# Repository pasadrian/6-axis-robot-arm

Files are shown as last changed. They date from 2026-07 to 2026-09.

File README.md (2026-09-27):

# 6-Axis Robotic Arm

## 1. Introduction
The main goal of this project was to create a 6-DoF robotic arm that is "mostly" 3D printed.  
\* "mostly" means that all custom parts are 3D printed, relying only on commonly available components like screws, timing belts, and ball bearings.

This approach provides several key benefits:
- **Modular construction**: 3D printing allows for easy design improvements and modular upgrades.
- **Easy maintenance**: Repairs are fast and cheap, eliminating the need to order specific parts.
- **Safety**: The lightweight design allows operators to work safely near the robot without the risk of serious injuries.

The arm's architecture is based on standard 6-DoF industrial manipulators. This makes it an ideal educational platform. It mimics the robots future engineers will encounter, but remains forgiving of operator mistakes.

---

## 2. Design
All 3D printed components were custom designed by the author in FreeCAD. The entire robot was manufactured using PLA on a Bambu Lab A1 printer equipped with a standard 0.4 mm nozzle.

---

## 3. Electronics & Actuation
- **Stepper Motors**: NEMA 17 and NEMA 23 stepper motors drive the primary axes, chosen for their torque and wide availability among hobbyists (see Chapter 5.1 in Masters_Thesis.pdf).
- **Servomotors**: The wrist and end effector utilize 180° servomotors. These are recommended for their low weight. Since most grippers are symmetrical, a 180° range is fully sufficient for standard operations.
- **Controller**: An STM32H755ZI-Q microcontroller serves as the main board, selected for its reliability, high processing speed, and hardware FPU necessary for real-time kinematics.

---

## 4. Control & Software
- **Communication**: A Serial (UART) connection is used to transmit data between the operator's PC and the STM32 board.
- **Interface**: The operator's GUI was developed in Python. It handles user inputs and sends movement commands directly to the microcontroller.

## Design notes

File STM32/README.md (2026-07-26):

# 6-axis-robot-arm
Project of a 3D printed 6axis robotic arm controlled with STM32 and Python GUI

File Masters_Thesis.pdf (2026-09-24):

AKADEMIA GÓRNICZO-HUTNICZA IM. STANISŁAWA STASZICA W KRAKOWIE

WYDZIAŁ ELEKTROTECHNIKI, AUTOMATYKI, INFORMATYKI I INZYNIERII BIOMEDYCZNEJ ˙

## Praca dyplomowa

## Design, Construction, and Control of a 6-DoF Robotic Arm Manufactured Using 3D Printing

## Projektowanie, budowa i sterowanie szescioosiowym ´ ramieniem robota wykonanym w technologii druku 3D

Autor: | inz. Adrian Pa ˙ | s´
Kierunek studiów: | Automatyka i Robotyka
Opiekun pracy: | dr hab. inz. Adam Piłat, prof. u. ˙

Kraków, 2026

## Contents

1 Introduction | 5
2 Literature review and existing solutions | 6
3 Project assumptions and constraints | 9
4 Mechanical design | 11
5 Actuation and electronics | 17
6 Mathematical model | 20

3

7 Software | 29
8 Validation and testing | 33
9 Conclusions | 41

4

A.Pas´ | Introduction

## 1 Introduction

### 1.1 Aim of this thesis

In modern factories, automation and robotization have become crucial in improving efficiency, precision, and safety. Industrial manipulators are increasingly used to replace or assist humans in tedious or hazardous tasks, such as palletizing, assembly, and conveyor belt operations. This generates a need for highly qualified engineers with the skills to design, program, and maintain robotic systems.
However, training future engineers on industrial robots is not practical due to the high cost of manipulators, costly fixing and maintenance, and the safety related to operating a machine with such a high payload. There is a clear need for affordable, safe, and easy to fix robots that mimic the kinematics and control used in industrial standards.
The main aim of this thesis is to design, construct, and evaluate a fully functional 6 DoF articulated robotic arm intended for educational purposes. The primary objective was to create a platform that mimics the configuration and control logic of industrial manipulators, while remaining safe for human interaction, affordable, and easy to maintain. Using 3D printing technology and combining an STM32 microcontroller with a Python control system, this project provides a perfect tool to study advanced robotics, such as inverse kinematics, joint synchronization, and path planning.

### 1.2 Scope of this thesis

This thesis is structured into several chapters that describe the entire process of designing, constructing, and programming the robotic arm, with functional testing of the physical platform. Following this introduction, Chapter 2 provides examples of existing robotic arms and similar open source projects. Chapter 3 defines the project assumptions, such as mechanical, electronic and safety constraints. In Chapters 4 and 5, these constraints are implemented, starting with mechanical design, CAD modeling, and torque calculations, to the selection of actuators, electronics, and the main control unit. Chapter 6 focuses on the mathematical model of the manipulator and explains forward and inverse kinematics with path planning and joint synchronization algorithms. Chapter 7 presents the software used, communication protocols, and the graphical user interface with the simulation tools. Chapter 8 evaluates the performance of the completed arm with load tests and trajectory verification. Finally, Chapter 9 provides a conclusion, summarizes the experimental results, and discusses potential real-life applications and future improvements for the system.

5

Literature review and existing solutions | A.Pas´

## 2 Literature review and existing solutions

The topic of robotic manipulators dates back to 1954, when the first hydraulic arm was invented and constructed in the United States.[1] Since then, many improvements have been made. Today, not only are there many types of robotic manipulators, but also most of them are equipped with numerous sensors and cameras.

### 2.1 Robotic manipulators - classification and application

Robotic arms can be divided into the classification presented in Fig. 1. Each of the constructions has its own advantages and disadvantages.

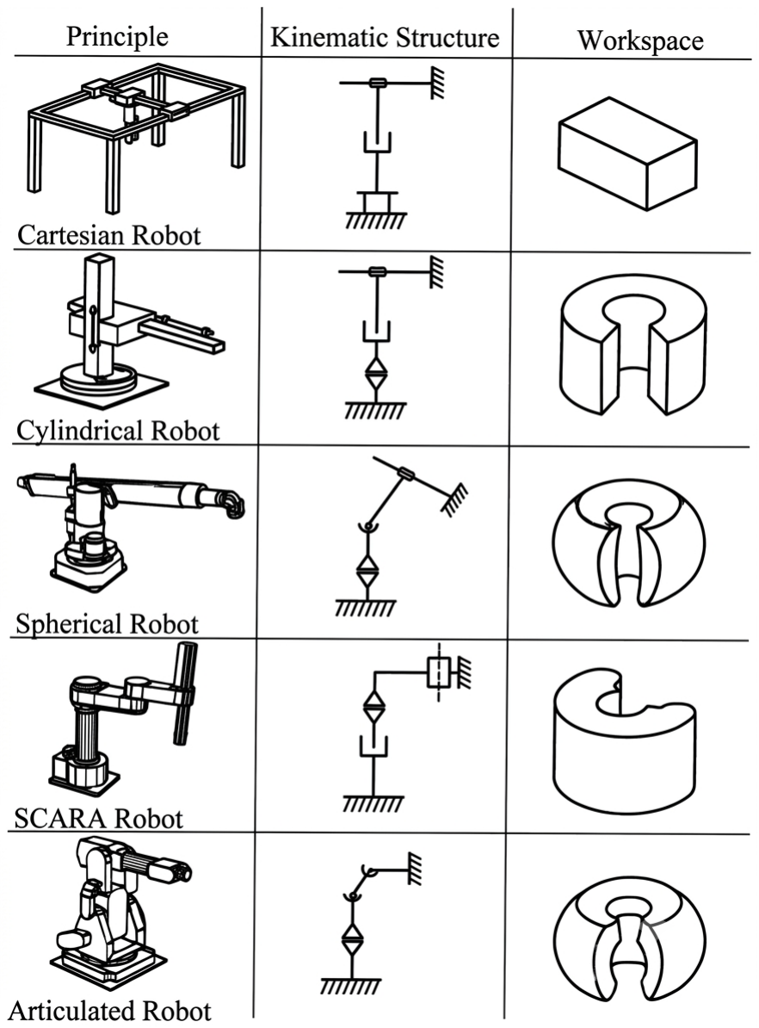
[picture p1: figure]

Figure 1. Classification of robotics manipulators [2].

The first group consists of cartesian manipulators, which are the simplest to control. The main drawback is the platform that has a large volume, usually greater than the robot’s workspace. The best example of this mechanism is an overhead crane.
The second category are robots that stand on their own on a rotating base. This type is the most common in industrial applications. For example, SCARA robots are commonly used by conveyor belts or whenever parts need to be moved with high precision. For other, general purpouse applications the articulated robots are almost always used. They have all of their joints as rotational, which allows for the greatest flexibility. This is the type of robot that is presented in this thesis. They can be found in assembly lines for cars, welding applications, or palletizing. That is why there are numerous brands that sell this type of robot. The most popular are Fanuc, Kuka, or ABB.

6

A.Pas´ | Literature review and existing solutions

### 2.2 Different ways of constructing a robotic arm

Robotic manipulators for industrial applications are generally made with metal as they need to be rigid to withstand huge loads. Because of that, their construction has a number of constraints. They are extremely heavy, require huge motors, consume a lot of power, and are dangerous to people standing in their operating range. All of those issues make it impractical for any other application than industrial applications.
Another way of making robotic arms is 3D printing. This technique allows for the creation of safer robots. Those plastic versions, although less accurate, repetable, or rigid, are the exact copy of the metal manipulators when it comes to construction. That makes them the perfect candidates for use in schools as a training tool for future engineers. In addition, if something goes wrong, making spare parts and fixing the 3d printed manipulator takes much less time and money.

### 2.3 Existing projects of 6-DoF manipulators

As robotic arms are extremely common in industrial applications, there is a great deal of them, ranging from big companies to hobbistic models. The following are some examples of the most popular ones.

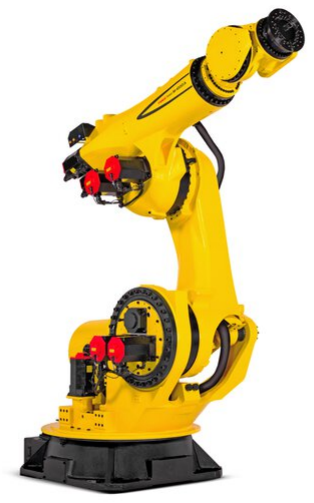
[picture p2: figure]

Figure 2. Fanuc M-1000iA [3].

7

Literature review and existing solutions | A.Pas´

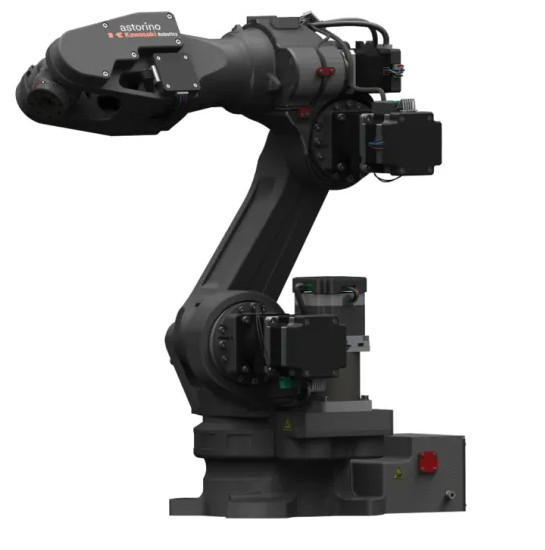
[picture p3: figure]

Figure 3. Educational robot Astorino [4].

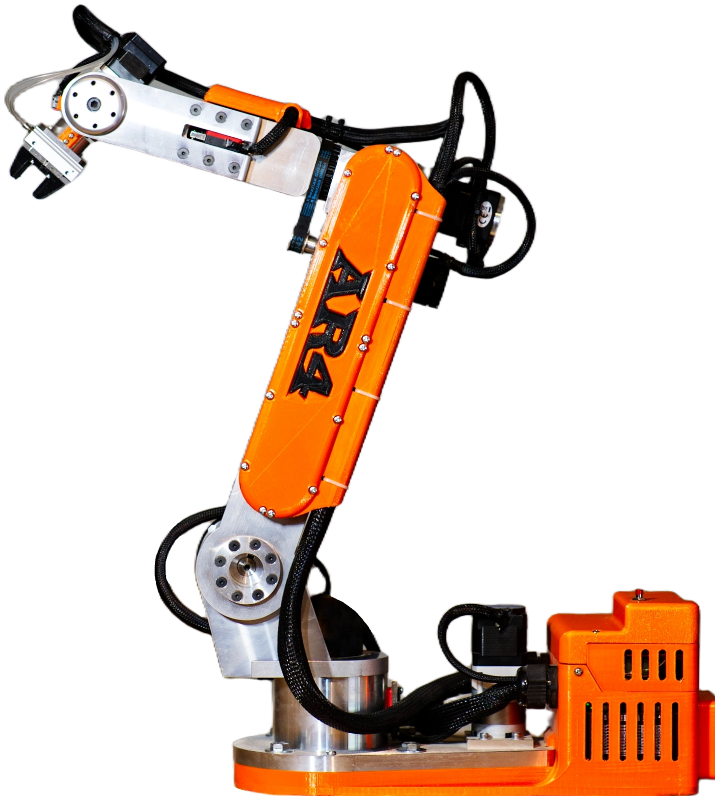
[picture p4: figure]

Figure 4. AR4 hobbist educational robot [5].

8

A.Pas´ | Project assumptions and constraints

## 3 Project assumptions and constraints

The main goal of this project was to design a manipulator that closely follows the architecture of industrial robotic arms while remaining safe for human interaction. To ensure that the robot is functional and reliable, several mechanical, operational, electronic, and safety constraints had to be defined.

### 3.1 Mechanical constraints

A key assumption was to implement a 6-degree-of-freedom (6-DOF) structure. This configuration mimics industrial standards, where the first three joints position the wrist in space and the remaining three determine the orientation of the end effector. This setup ensures that the control logic and kinematics of the robot are kept similar to those of the industrial manipulators. Material selection was another important constraint. Since the robot is mostly 3D-printed, it was necessary to choose a filament that balances ease of printing with structural integrity. The chosen material had to provide enough precision for the gear teeth and bearings while being fast enough to print larger components. The final design aims to be rigid enough to prevent flexing under its own weight, yet light enough to be powered by hobbyist-grade motors.

### 3.2 Operational parameters

The operational group of assumptions involves the robot’s physical capabilities, such as reach and motion limits

– Reach: The maximum reach was determined by the 3D printer’s build plate size. Arm
| links were designed to be as large as the printer could handle.

– Motion Limits: Each joint has a defined range of motion for two reasons. First, it pre-
| vents cables from tangling or breaking during rotation. Second, it allows the use of limit
| switches for the homing procedure, which establishes a "zero" position in space.

– Load Capacity: High strength was not a priority for this project. Since the structure
| is plastic, heavy loads could cause the links to bend or crack over time. The robot is
| intended for light tasks, such as moving small objects or playing board games, where the
load is negligible.

### 3.3 Electronic constraints

Electronic constraints are just as important as mechanical ones and can be divided into three categories: the main control unit, the motors, and the power supply.

| 9

Project assumptions and constraints | A.Pas´

The main constraint in selecting the control unit was computational performance. For a six degree of freedom manipulator, the kinematics equations are quite heavy, so a board with a high speed microprocessor and floating point support was necessary. Another factor was the number of inputs and outputs. Since the project uses many motors, limit switches, and sensors, the board must handle all of them simultaneously without any lag.
The second group of components are the motors. Here, torque, weight, cost, and power consumption needed to be balanced. A compromise had to be established between all these parameters. For the base axis, which holds the weight of the entire arm, torque was the priority over weight and cost. However, for the joints further up the arm, weight became the most important factor, the lighter the motor, the better. The overall cost was kept low since this is a hobbyist project made of 3D printed plastic parts, and using expensive industrial motors would be overkill.
The last thing to consider was the power supply. The main power consumption comes from the motors. It was assumed that the operating voltage should be maximized within the limits of the drivers. This will ensure that the motors maintain a high level of torque, even at higher speeds.

### 3.4 Safety constraints

The safety constraints in this project are mainly focused on the control and motion of the robotic arm. Unlike heavy industrial robots made of steel, which can pose a significant danger to operators, the manipulator built in this thesis is 3D printed and operates at lower power levels. This design results in a much lower risk for humans as the motors do not provide enough force to cause serious injury.
The main safety concerns are actually related to the robot itself, as collisions with other objects could easily damage the manipulator. To prevent this, software limitations were implemented. The first was the virtual boundarie to keep the end effector from hitting the ground and other known obstacles. The second was to limit each joint to make it work within a safe operating range so that the robot would not tangle its cables or hit itself.

10

A.Pas´ | Mechanical design

## 4 Mechanical design

The robotic arm was fully designed and built by the author of this thesis. The design is based on standard robotic manipulators, but the main goal was to see how many parts could be 3D printed. Using 3D printing makes the robot much easier to repair because there is no need to wait for expensive or specialized parts from a shop. If something breaks, a new part can be printed.
The entire project was designed in FreeCAD. This program was chosen because it is free and works locally on the computer, so it does not require a cloud connection or a user account. Additionally, using this software means the author has full control and ownership of all the designs without any licensing problems.

### 4.1 CAD model of the manipulator

The following figure shows the complete 3D model of the robotic arm (without the gripper), with a list of parts on the left.

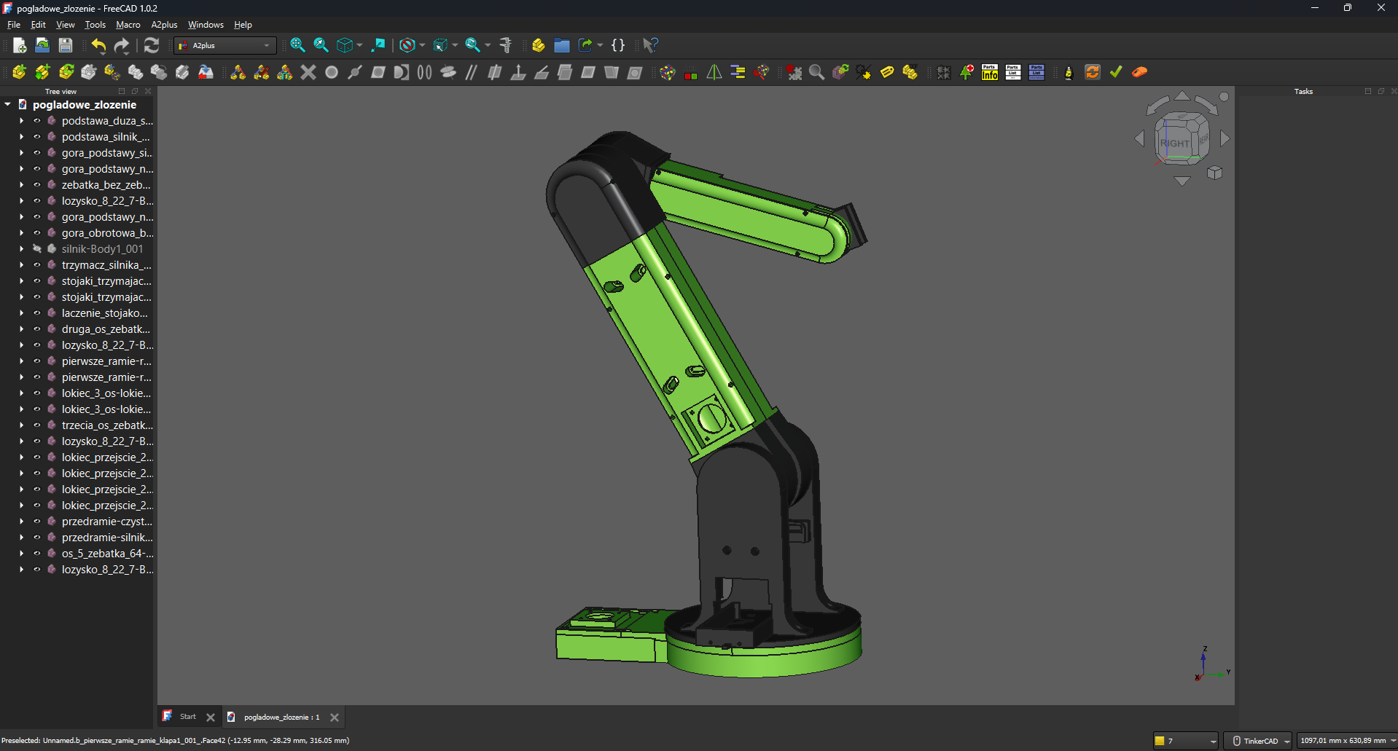
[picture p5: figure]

Figure 5. Complete model of the robotic arm in FreeCAD. Source: Own work

The manipulator consists of 24 3D-printed parts, including:

– gears with 32, 64, and 128 teeth,

– custom-designed "lazy susan" ball bearings,

– timing belt tensioners.

11

Mechanical design | A.Pas´

Specialized bearings were designed for the main base turntable, the elbow, and the forearm. This helped reduce the overall weight of the robot and, more importantly, allowed custom bearing sizes that perfectly fit the design. These bearings use 5mm metal balls and a 3D-printed race with even spacing to keep the balls in place while allowing them to spin freely. As mentioned

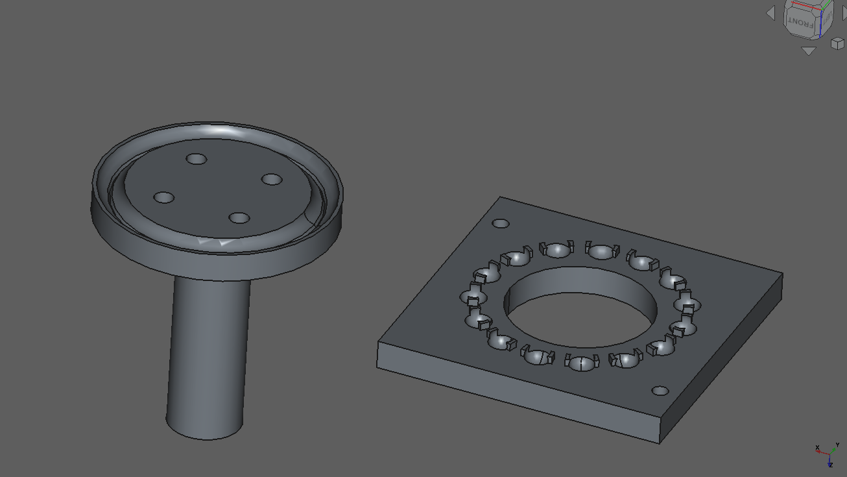
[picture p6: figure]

Figure 6. Custom ball bearing design. Source: Own work

above, the main goal was to design a functional robotic arm using as few standard parts as possible. In addition to electronics, the only components that need to be purchased are threaded inserts, screws, small standard bearings, timing belts, and metal balls.
Although these parts must be purchased, they are all standard, widely available products. They are not specific to this single project, so they are always in stock and easy to find. This fulfills the main goal of the thesis: creating a robotic arm primarily from 3D-printed materials without being dependent on specialized suppliers.

### 4.2 Mechanical specifications and dimensions

After completing the CAD model, the physical limits and dimensions of the manipulator were established. Defining these parameters is essential for understanding the robot’s workspace and for future calculations in the control software.
The reach of the robot is determined by the lengths of the individual links measured between the rotation axes of the joints.

– Base height (Link 0): 187.3 mm – from the ground to the center of the shoulder joint.

12

A.Pas´ | Mechanical design

– Upper arm (Link 1): 335.6 mm – from the shoulder to the elbow joint.

– Forearm (Link 2): 228.6 mm - from the elbow to the center of the wrist.

– Wrist to TCP (Link 3): 212 mm – from the center of the wrist to the end of the gripper.

To provide a quick overview of the robot’s capabilities, the most important technical specifications are presented in the table below.

Table 1. General technical specifications of the manipulator.

Parameter | Value
Architecture | 6-Axis Articulated Robot
Maximum Reach (Radius) | 776.2 mm
Total Weight | approx. 4.4 kg
Main Material | PLA (3D Printed)
Drive System | NEMA 17 and 23 Stepper Motors
Transmission | GT2 Timing Belts / 3D Printed Gears
Estimated Payload | Up to 500 g with 1/16 microsteps
Base Diameter | 220 mm

### 4.3 Calculating torque for two main joints

To ensure that the stepper motors were capable of holding the manipulator, it was necessary to calculate the required torque for the two main joints, the second and third, which are the most stressed during the operations. The most demanding position is when the robotic arm is fully extended horizontally.
The torque for each individual part was calculated using the following formula:
M = m · g · r | (1)
where m is the mass of the component in kg, g is the gravitational acceleration (9.81 m/s² | ), and

r is the distance from the center of mass of the part to the axis of the joint in meters.
The mass of each 3D-printed part was obtained from the Bambu Studio slicer, while the mass of the motors was taken from their datasheets [6]. For these calculations, it was assumed that the center of gravity for each part lies at its geometric center. The weight of minor components such as screws, nuts, and timing belts was considered negligible.
The table below presents the torque calculation for the second joint (Shoulder), which uses a NEMA 23 motor.

13

Mechanical design | A.Pas´

Table 2. Torque calculation for Nema23 (Axis 2)

Item | Weight [kg] Center of Gravity [m] Torque [Nm]
nema17 + bearing | 0.289 | 0.070 | 0.201
arm bearing | 0.012 | 0.179 | 0.021
arm | 0.210 | 0.154 | 0.324
arm gear | 0.014 | 0.179 | 0.025
elbow | 0.089 | 0.319 | 0.284
elbow gear | 0.041 | 0.334 | 0.137
elbow bearing | 0.012 | 0.334 | 0.038
entire elbow | 0.084 | 0.334 | 0.282
nema17 + bearing (2) | 0.289 | 0.294 | 0.849
small motor | 0.132 | 0.405 | 0.535
forearm | 0.104 | 0.480 | 0.497
axis 5 bearings | 0.012 | 0.567 | 0.065
axis 5 gear | 0.014 | 0.567 | 0.081
axis 6 holder | 0.015 | 0.605 | 0.088
servo sg995 | 0.055 | 0.620 | 0.341
pointer | 0.011 | 0.711 | 0.080
Total Sum | | | 3.847

The total torque of 3.85 Nm is higher than the maximum holding torque for the chosen Nema23 motor (57HS112-3004), which is around 3 Nm in the datasheet [7]. To overcome this, a gear ratio of 128:20 (6.4:1) was applied on this axis.
The same was done for the third joint (Elbow).

14

A.Pas´ | Mechanical design

Table 3. Torque calculation for Nema17 (Axis 3)

Item | Weight [kg] Center of Gravity [m] Torque [Nm]
nema17 + bearing | 0.289 | -0.040 | -0.115
small motor | 0.132 | 0.071 | 0.092
forearm | 0.104 | 0.146 | 0.148
axis 5 bearings | 0.012 | 0.233 | 0.026
axis 5 gear | 0.014 | 0.233 | 0.033
axis 6 holder | 0.015 | 0.271 | 0.039
servo sg995 | 0.055 | 0.286 | 0.154
pointer | 0.011 | 0.377 | 0.042
Total Sum | | | 0.419

Here again, the total torque exceeds the maximum holding torque for the motor used Nema17 (HS4401), which is 0.4 Nm according to the datasheet [6].To overcome this, a gear ratio of 8:1 was applied on this axis.

### 4.4 Optimalization for 3D printing

Optimizing the design for 3D printing is an essential part of the process. Several constraints and techniques must be considered during the design phase.

– The size of the 3D printer build plate.

– The printer’s precision and layer height.

– Wall thickness and infill percentage.

– Printing time, while not the most critical factor, printing smaller parts reduces the risk of total failure during long jobs.

The printer used for this project was a Bambu Lab A1. It has a build volume of 256 × 256 × 256 mm³
. All parts were printed using a standard 0.4 mm nozzle, as it provides a good balance between printing speed and detail. The layer height was set to 0.2 mm. To ensure that parts are strong enough but still lightweight, most structural elements were designed with a total thickness of 5 mm. This thickness consists of 3 layers of the outer wall on each side, with a 15% infill between. This combination provides great rigidity while keeping the weight of the robotic arm low.
In addition to these settings, certain design techniques can significantly improve the quality of the robot.

15

Mechanical design | A.Pas´

– Proper orientation of the object on the build plate.

– Using supports only where necessary.

– Splitting large designs into smaller, connected parts.

In Fused Deposition Modeling (FDM) in 3D printing, the internal bond of the filament is almost always stronger than the adhesive bond between the printed layers [8]. Because of this, the printing orientation was the most important parameter. Choosing the right orientation was always a priority, even if it required more supports or a longer printing time.

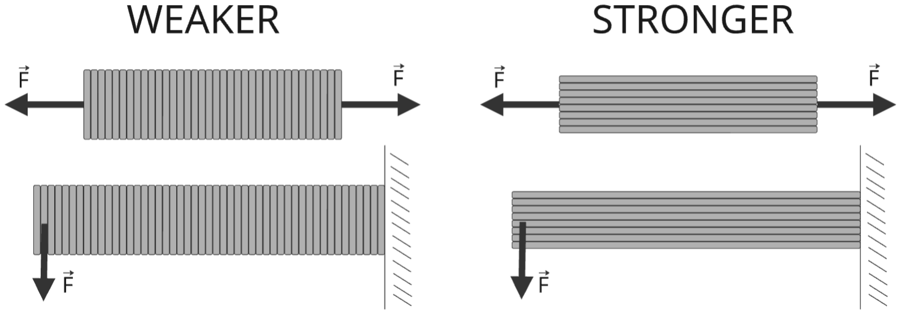
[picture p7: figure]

Figure 7. Comparison of strength based on printing orientation. Source: Own work

Another important factor is deciding when to use supports. A good way to optimize the design is to eliminate the need for supports by changing the geometry. For example, a 90-degree overhang can often be replaced with a slope (chamfer) to make it self-supporting. This saves material and avoids the "ragged" surface finish that supports often leave behind.
The final technique used was to split the design into smaller components. Although it is usually easier to print one large part, splitting is useful in two cases. First, it allows for better access to the inside of a part to install gears or cables. Second, it makes assembly easier by providing more space for tools, such as screwdrivers, during the final build.

16

A.Pas´ | Actuation and electronics

## 5 Actuation and electronics

### 5.1 Motors with gears

When selecting drivers in robotics there are two main options to consider, servomechanizm or stepper motor. The servomechanizm is every DC or AC motor with closed control loop, for example, brushless motor with encoder and PID controler which allows it to reach the desired position. The second type is a stepper motor. This driver does not require feedback, it can be controlled in an open loop, as it does not rotate freely, but takes steps. This type of motor is more common in hobby designs, as it is easier to use and cheaper.
In this project, both stepper and servomotors are used. The first five axes are equipped with Nema23 and Nema17 stepper motors, while the sixth axis and gripper use servo 180. Nema stepper motors were chosen as they have a high torque while being affortable. Every stepper motor has 200 steps per revolution [6] and is set to work with 1/16 microstepping. In addition, to achieve higher precision, gear ratios were used for all axes. The resulting resolution for each joint is summarized below:

Table 4. Kinematic parameters and step resolution for each axis.

Axis | Motor Type | Gear Ratio Steps/Rev Resolution [◦
/step]
1 | Nema17 HS4401 | 8:1 | 25,600 | 0.01406
2 | Nema23 57HS112-3004 | 128:20 | 20,480 | 0.01758
3 | Nema17 HS4401 | 8:1 | 25,600 | 0.01406
4 | Nema17 HS4401 | 1:1 | 3,200 | 0.11250
5 | Nema17 HS4023 | 4:1 | 12,800 | 0.02812
6 | Servo SG995 | 1:1 | N/A | N/A

Based on the data in Table 4 some observations can be made. The precision on the first three axes, which are responsible for positioning the wrist of the robot in a space, is less than 0.02◦

per step, which is more than enough for simple pick and place operations. The fourth axis has the lowest precision and no gear ratio, because it only rotates the forearm of the robot. The sixth axis is equipped with a servomotor that can rotate in 180◦
and its resolution is based mainly on applied control via PWM signal.
Another aspect of gear ratio is the increase in a torque liniary to the ratio applied. The torques for each motor can be seen in the following table:

17

Actuation and electronics | A.Pas´

Table 5. The torques of each motor. [6], [9], [10], [7]

Axis | Motor Type | Motor’s torque [Nm] Gear Ratio Joint’s torque [Nm]
1 | Nema17 HS4401 | 0.4 | 8:1 | 3.2
2 | Nema23 57HS112-3004 | 3 | 128:20 | 19.2
3 | Nema17 HS4401 | 0.4 | 8:1 | 3.2
4 | Nema17 HS4401 | 0.4 | 1:1 | 0.4
5 | Nema17 HS4023 | 0.14 | 4:1 | 1.6
6 | Servo SG995 | 1 | 1:1 | 1

Motors and gear ratios were chosen independently for each joint. As the second axis holds the whole robotic arm it had to be the strongest one. The first, third and fourth axes were given the same motor, but different gear ratios. Although the first and third have some load to overcome, the fourth joint does not need much strength since it only spins the forearm. The fifth axis was equipped with a smaller Nema17 motor to reduce weight. The last sixth axis has serwo 180◦
. With the assumption that every gripper used in its build is simetrical, there was no need for a more advanced motor.

### 5.2 Positioning and feedback

To accurately position the robotic arm in 3D space, it is essential to establish a reference coordinate system. This is achieved with a process known as homing. The manipulator is equipped with five end-stop sensors, one for each axis. During homing, the control system sets the speed of each motor to the slow safety value and sets the direction to move toward the endstop. When end-stop is activated, the link stops and waits for other to finish homing. Once all of the joints are finished, the robot sets this position as home to know the relative orientation of each axes. From now on, the controller tracks the position of the stepper motors based on the amount of steps each took. Since stepper motors provide predictable motion, they can operate effectively without external feedback, assuming that the load does not exceed the motor’s holding torque, which would result in lost steps. Similarly, the 180◦
servomotor does not need external feedback, as its closed loop circuitry maintains the shaft position based on the width of the incoming PWM (Pulse Width Modulation) signal.

### 5.3 Control unit - uC, drivers

The STM32H755ZI-Q microcontroller was selected as the central processing unit for the robotic manipulator. It is an extremely powerful board characterized by the following parameters [11]:

18

A.Pas´ | Actuation and electronics
- Dual-core architecture: Featuring Cortex-M7 and Cortex-M4 cores with a clock speed of up to 480 MHz. This high computational power, supported by a hardware Floating Point Unit (FPU), is essential for real time Inverse Kinematics (IK) calculations and trajectory planning.
- Extensive I/O capabilities: Up to 114 I/O ports with interrupt support. This allows for future upgrades, such as implementing closed loop control with encoders on each axis, adding extra sensors, or integrating manual control interfaces.
- Advanced Timers (PWM): High resolution timers allow for precise PWM generation to control servos and provide stable interrupt signals for stepper motor drivers, to keep the motor speeds as it was planned.
- Communication Protocols: A wide range of interfaces including I2C, SPI, and UART, which was used in this project for remote robot control.

While simpler controllers would be suitable for this application, this high-performance board is ideal for future expanding the robot’s capabilities.
Each stepper motor is equipped with its own driver. For the Nema23 motor on the second axis, a DM556 driver was used to handle a higher current and provide greater torque. The remaining axes use TMC2209 drivers, chosen for their quiet operation and smooth motion control.

### 5.4 Electronic diagram

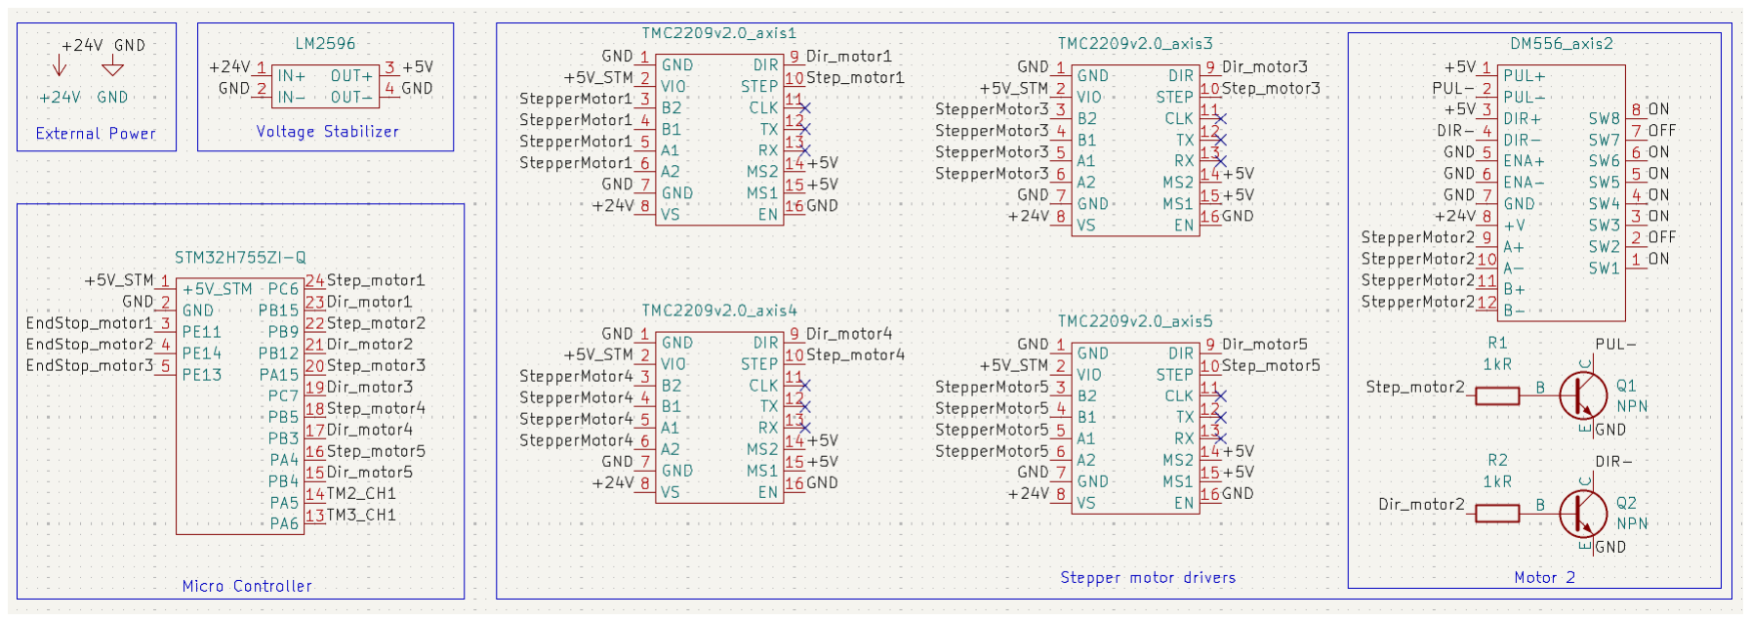
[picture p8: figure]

Figure 8. Electrical scheme. Source: Own work

19

Mathematical model | A.Pas´

## 6 Mathematical model

This chapter is based on the work presented in [12].

### 6.1 Froward kinematics

To successfully control a robotic manipulator, it is essential to understand how the arrangement of each joint affects the position and orientation of the end effector. Based on the length of each robot’s link and the angels at which the joints are set, the exact pose of the manipulator’s end effector can be calculated. For 6-DOF robotic arms, the Denavit–Hartenberg convention is used. This method describes rotation and translation between consecutive joints with standarised parameters, as shown in the table below.

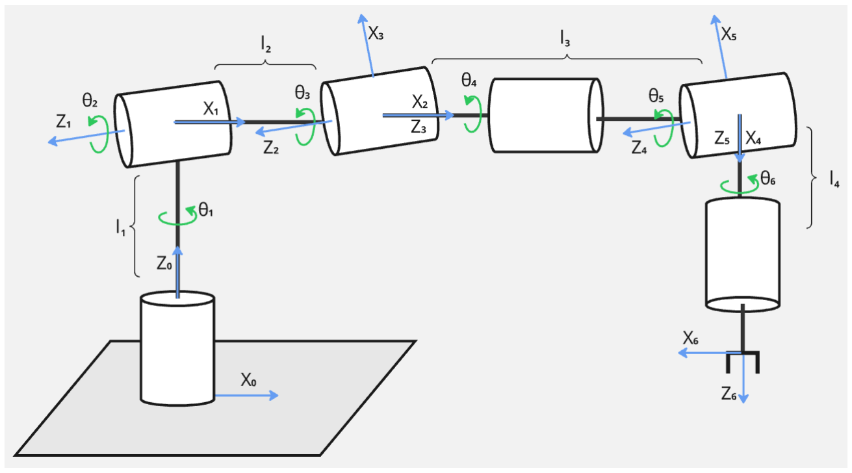
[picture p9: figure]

Figure 9. Rotation frames for my robot. Source: Own work

These parameters can be applied to the general D-H matrix (2), which describes the rotation and translation of the joint-link pair.

Ti =

cos θi | − sin θi cos αi | sin θi sin αi | ai cos θi
sin θi | cos θi cos αi | − cos θi sin αi | ai sin θi
0 | sin αi | cos αi | di
0 | 0 | 0 | 1

(2)

By substituting the values into the matrix, we get the following 6 matrices.

20

A.Pas´ | Mathematical model

Table 6. Denavit–Hartenberg parameters for 6-DOF robotic arm.

i | ai | αi | di | θi
1 | 0 | +π
| | 2 | l1 | θ1
2 l2 | 0 | 0 | θ2
3 l3 | 0 | 0 | θ3
4 | 0 | +π
| | 2 | 0 | θ4
5 | 0 | − π
| | 2 | 0 | θ5
6 | 0 | 0 | l4 | θ6

T1 =

cos θ1 | 0 | sin θ1 | 0
sin θ1 | 0 − cos θ1 | 0
0 | 1 | 0 | l1
0 | 0 | 0 | 1

(3)

T2 =

cos θ2 | − sin θ2 | 0 l2 cos θ2
sin θ2 | cos θ2 | 0 l2 sin θ2
0 | 0 | 1 | 0
0 | 0 | 0 | 1

(4)

T3 =

cos θ3 | − sin θ3 | 0 l3 cos θ3
sin θ3 | cos θ3 | 0 l3 sin θ3
0 | 0 | 1 | 0
0 | 0 | 0 | 1

(5)

T4 =

cos θ4 | 0 | sin θ4 | 0
sin θ4 | 0 − cos θ4 | 0
0 | 1 | 0 | 0
0 | 0 | 0 | 1

(6)

T5 =

cos θ5 | 0 | − sin θ5 | 0
sin θ5 | 0 | cos θ5 | 0
0 | −1 | 0 | 0
0 | 0 | 0 | 1

(7)

T6 =

cos θ6 | − sin θ6 | 0 0
sin θ6 | cos θ6 | 0 0
0 | 0 | 1 l4
0 | 0 | 0 1

(8)

21

Mathematical model | A.Pas´

Because the movement of the earlier joints influences the pose of all of the following joints, multiplying the matrices results in the final homogeneous transformation matrix defining the end effector pose relative to the base of the robot.

T

0
6 = T1 T2 T3 T4 T5 T6 =

"
R3×3 | p3×1
01×3 | 1
, | (9)

Where R3x3 is a rotation matrix and p3x1 is a vector of the position of the end effector.

### 6.2 Inverse kinematics

When dealing with robotic manipulators, one of the fundamental problems is determining the angles of each joint to achieve the required position and orientation of the end effector. This problem, known as inverse kinematics, is not trivial. Firstly, there can be more than one solution or no solution at all for the given configuration of the end effector. Additionally, not every manipulator has an analytical closed form solution for the inverse kinematics. There are two conditions that must be met. The first one is that three of the manipulator’s joints must be parrarel. The second is that there needs to be a sphirical joint, which means that three of its joints must have a rotation axis that intersects in a common point. The robot described in this thesis meets those requirements, which allows the inverse kinematics problem to be solved. As a starting point, the homogeneous transformation matrix T
0/6 is given. As explained in the previous chapter, this matrix contains a rotation matrix R⁰
6

and a position vector P

0
6 of the
end effector.
Due to the presence of a spherical wrist, the inverse kinematics problem can be divided into two independent ones. The first three joints are responsible for the position of the robot’s wrist, while the last three define its orientation. With that, the problem comes to computing the position of the wrist and the orientation R⁶
3 of the last three joints. First, by moving one joint back from the known location of the end effector, the exact position of the wrist can be calculated.

W =

wx
wy
wz

- =

px − d6r13

py − d6r23

pz − d6r33

- (10)

Here, the position is taken from P

0
6 = [px, py, pz]

T

and rnm is taken from R⁰
6

### 6.2.1 Position of the wrist

With the wrist pose known, the first part of the problem can simply be referred to as follows.

22

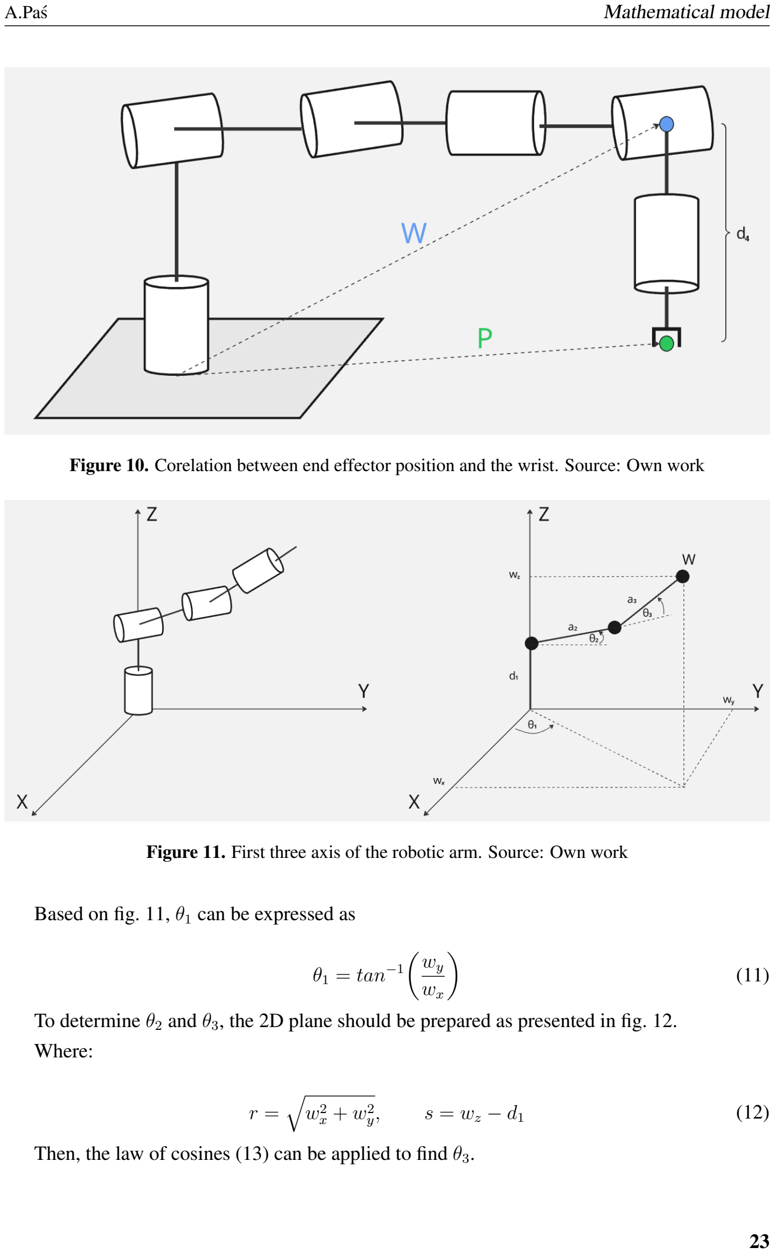
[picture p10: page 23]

A.Pas´ | Mathematical model

Figure 10. Corelation between end effector position and the wrist. Source: Own work

Figure 11. First three axis of the robotic arm. Source: Own work

Based on fig. 11, θ1 can be expressed as

θ1 = tan⁻¹

wy
wx
(11)

To determine θ2 and θ3, the 2D plane should be prepared as presented in fig. 12. Where:

r =

q
w²

x + w²
y

, s = wz − d1
(12)

Then, the law of cosines (13) can be applied to find θ3.

23

Mathematical model | A.Pas´

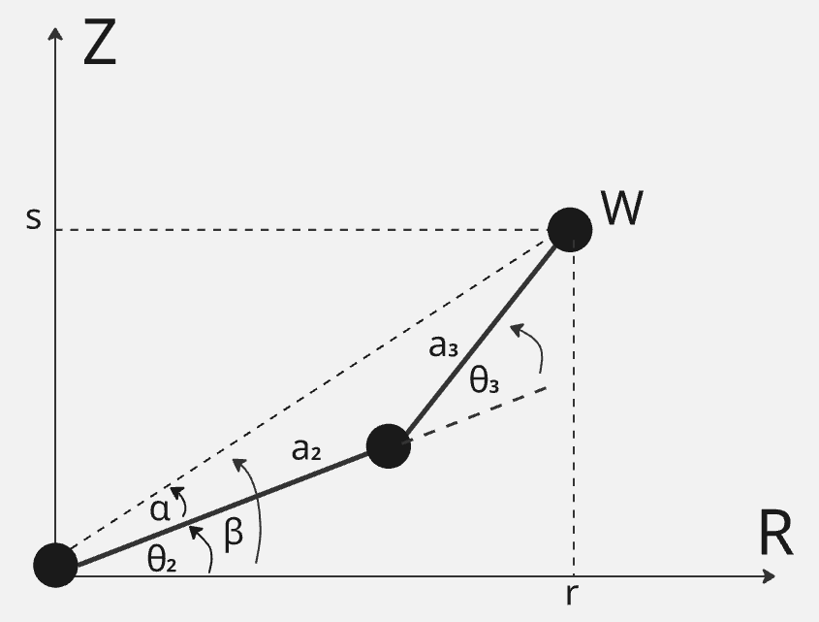
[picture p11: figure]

Figure 12. 2D plane with first and second manipulator’s arms. Source: Own work

c

2 = a

2 + b

2 − 2ab cos γ | (13)

With values assigned earlier, the final equation takes the following form:

θ3 = cos⁻¹

r

2 + s

2 − a

2
2 − a

2
3
2a2a3
| (14)

The final step is to determine θ2, which can be calculated as θ2 = α − β, where the angles

are defined as
α = atan2(s, r) | (15)
β = atan2(a3 sin θ3, a2 + a3 cos θ3) | (16)
θ2 = atan2(s, r) − atan2(a3 sin θ3, a2 + a3 cos θ3) | (17)

### 6.2.2 Orientation of the wrist

Now, the wrist orientation must be calculated. It is represented by the matrix R³
6
| , which can be
calculated from:
R

3
6 =
R

0/3T
R

0
6 | (18)

The R⁰
6

is known because it is our desired orientation. The R⁰
3
can be taken from T | 0/3, which is
the multiplication of the matrices T1..3 from the previous chapter and is equal to

24

A.Pas´ | Mathematical model

T

3
0 =

c1c23 | −c1s23 | s1 | wx
s1c23 | −s1s23 | −c1 | wy
s23 | c23 | 0 | wz
0 | 0 | 0 | 1

(19)

The same can be done with the matrix R³
6

, as it is a part of the transformation matrix T 3/6,
which is a multiplication of matrices T4..6.

T

3
6 =

c4c5c6 − s4s6 | −c4c5s6 − s4c6 | c4s5 | px
s4c5c6 + c4s6 | −s4c5s6 + c4c6 | s4s5 | py
−s5c6 | s5s6 | c5 | pz
0 | 0 | 0 | 1

(20)

Now, substituting the rotation matrices into the equation (18) and performing the transformation, the following equation is obtained.
c4c5c6 − s4s6 | −c4c5s6 − s4c6 | c4s5
s4c5c6 + c4s6 | −s4c5s6 + c4c6 | s4s5
−s5c6 | s5s6 | c5

- =

c1c23 | s1c23 | s23
−c1s23 | −s1s23 | c23
s1 | −c1 | 0

r11 | r12 | r13
r21 | r22 | r23
r31 | r32 | r33

(21)

From this equality five crucial equations can be written:

c4s5 = c1c23r13 + s1c23r23 + s23r33 | (22)
s4s5 = −c1s23r13 − s1s23r23 + c23r33 | (23)
c5 = s1r13 − c1s23 | (24)
s5s6 = s1r12 − c1r22 | (25)
−s5c6 = s1r11 − c1r22 | (26)

Now, the three remaining angles θ4, θ5, and θ6 depend only on the angles determined previously. For θ5 first the sin(θ5) can be calulated and then used in the atan2 function.

s5 =

q
1 − c

2
5 | (27)

θ5 = atan2
±

p
1 − (s1r13 − c1r23)

2

, s1r13 − c1r23
(28)

25

Mathematical model | A.Pas´

By dividing equations (23) and (22), θ4 can be obtained.

θ4 = atan2

− c1s23r13 − s1s23r23 + c23r33, c1c23r13 + s1c23r23 + s23r33
(29)

Identical for the last angle, by taking (25) and (26) and dividing them, θ6 can be obtained:

θ6 = atan2
s1r12 − c1r22, −s1r11 + c1r22
(30)

### 6.3 Summary of inverse kinematics and constraints

The equations presented in the following allow to calculate the required angles for all six joints.

θ1 = tan⁻¹

wy
wx
(11)
θ2 = atan2(s, r) − atan2(a3 sin θ3, a2 + a3 cos θ3) | (17)

θ3 = cos⁻¹

r

2 + s

2 − a

2
2 − a

2
3
2a2a3
| (14)

θ4 = atan2

− c1s23r13 − s1s23r23 + c23r33, c1c23r13 + s1c23r23 + s23r33 | (29)

θ5 = atan2
±

p
1 − (s1r13 − c1r23)

2

, s1r13 − c1r23 | (28)

θ6 = atan2
s1r12 − c1r22, −s1r11 + c1r22 | (30)

In theory, this system of equations can result in up to 8 different sets of solutions for a single target position. For example, the robot could reach a point with its "elbow" pointing up or down. To make sure that the robot’s motion is predictable, there is an algorithm that always prioritizes the same solution from the available ones. This means that if both solutions are allowed by the set limits of the robot, the software will always choose the same one.
In this project, no joint rotates by more than 180 degrees. This restriction is mainly made to ensure that cables do not get tangled, but it also helps the IK by removing some of the theoretical solutions. The operational ranges for each joint are presented in the table below.

Table 7. Software and mechanical limits for each joint.

Joint | Minimum Angle | Maximum Angle
θ1 (Base) | -90.0° | 45.0°
θ2 (Shoulder) | 10.0° | 135.0°
θ3 (Elbow) | -170.0° | 0.0°
θ4 (Wrist Roll) | -90.0° | 90.0°
θ5 (Wrist Pitch) | -90.0° | 90.0°
θ6 (Wrist Yaw) | -90.0° | 90.0°

26

A.Pas´ | Mathematical model

Another critical aspect of the movement is the presence of singularities. A singularity occurs when two or more axes align in a straight line, causing the robot to lose a degree of freedom. The most common example is the position where the wrist is located directly above the base. In this state, the calculation for θ1 becomes unstable because any rotation of the base results in the same tool position. To ensure correct operation, the software constantly checks for known singularities and prevents the robot from entering them.

### 6.4 Algorithms of TCP control

The Tool Center Point (TCP) algorithm is a control method designed to move a robotic arm’s end effector along a specific trajectory while keeping the pose or orientation. This is essential in practical applications, such as

– Palletization tasks: Where a robot must move an object from point A to point B while keeping it perfectly level or at a specific angle.

– Welding or gluing: Where the distance and angle to the surface must be kept constant throughout the whole movement.

To make the algorithm work correctly, there are three functions that need to be implemented:

### 6.4.1 Path linearization and interpolation

Since the main goal of TCP movement is controlling the trajectory, the desired path needs to be "forced" onto the robotic arm. This is done by dividing the long path into many small segments. Without this division, the manipulator would move in a trajectory that is efficient for its joints but completely unpredictable for the user. Using smaller steps, the robot is forced to visit each point in sequence. If these points are close enough together, the robot basically moves in the exact straight line it was told to follow. Additionally, managing these shorter steps makes it much easier to keep the end effector in the desired orientation throughout the whole move.

### 6.4.2 Joint synchronization

Once the path is divided into microsteps, the movements of all six joints must be synchronized. If the joints operated independently, some might reach their target position faster than others, resulting in a jittery motion where the robot repeatedly stops and starts. In a synchronized system, the controller calculates the necessary velocity for each axis so that they all start and finish each microstep simultaneously. This ensures a smooth, continuous motion of the Tool Center Point.
In this project, the synchronization was implemented by choosing the leading joint. The process follows these steps:

27

Mathematical model | A.Pas´

– Step to angle conversion: First, the software takes the target angles from the IK equations and calculates the exact number of steps each motor must perform.

– Identifying the bottleneck: Using the predefined maximum safe speed for each motor, the controller calculates the minimum time required for each joint to complete its portion of the move:

tjoint =

steps to perform
max speed [steps/s]

– Leading joint selection: The joint that requires the most time to finish its move becomes the leading joint. This joint will move at its maximum allowed speed, acting as the speed bottleneck for the entire system.

– Velocity scaling: To ensure all motors finish at the exact same time, the speeds of the remaining five joints are scaled down proportionally:

Target Speedn =

stepsn

tlead

This approach ensures two things. First, all movements are safe because no motor ever exceeds its set speed limit. Second, all joints start and finish their rotation at the same time, eliminating the need for any motor to stop and wait, resulting in smooth continuous motion.

### 6.4.3 Look-ahead and velocity planning

To achieve smooth motion, the robot should avoid unnecessary acceleration and deceleration at every intermediate point. This is managed through Look-Ahead planning. Instead of just looking at the current move, the algorithm calculates several points in advance to analyze the next segments of the path. It checks each individual joint to see if it needs to continue moving in the same direction or not. If the direction stays the same, the controller prevents the motor from decelerating and maintains its current speed. However, if an axis needs to stop or change direction in the next step, the system starts to decelerate early to prepare for that change. This approach allows the robot to operate at its maximum efficient speed while maintaining mechanical stability and avoiding jerky movements.

28

A.Pas´ | Software

## 7 Software

Several different software tools were used to complete this thesis. Programs like FreeCAD, Bambulab Studio, and KiCad were used mainly for mechanical and electrical design. On the other hand, Python and STM32CubeIDE were chosen to handle the robot’s control system and all its functionalities.

### 7.1 Programming languages used

Two main programming languages were used in this project: Python for the high-level control on the PC, and C for the low-level logic running on the STM32 mainboard.

### 7.1.1 Python

Python was chosen because it is one of the best languages for creating a Graphical User Interface (GUI) for easy remote control. It offers numerous libraries that simplify development. One of them is Tkinter, which was used to set up the control window with buttons, sliders, and text boxes. Additionally, the NumPy library was used to handle all the complex matrix calculations needed for the robot’s movement. To make the system easier to debug, the Matplotlib library was also implemented to create a 3D simulation of the robot. This allows the user to visualize and test the trajectory on the screen before the real robotic arm starts moving.

### 7.1.2 C

C was chosen as it is the main language used in STM32CubeIDE. It is a very efficient and fast language that gives the programmer great control over the hardware. This speed is essential for a robot controller that needs to work in real-time, especially when calculating Inverse Kinematics (IK) and checking safety constraints simultaneously. Using C also allows for direct management of the microcontroller’s internal timers and interrupts, which is crucial for generating precise steps for the motors and responding to sensor data without any delay.

### 7.2 Communication computer - robot

Several communication methods were possible, but a serial connection (UART) was chosen for this project. It is easy to set up over a standard USB port that connects the computer directly to the STM32 board. This standard is fast enough to ensure that there is no visible delay between sending a command and the robot performing the movement. A baud rate of 115200 was selected as it offers a great balance between communication speed and data reliability.

29

Software | A.Pas´

Most of the communication is one-way, following a "command-action" structure. The computer sends a specific data packet that the board receives, processes, and then executes. To ensure that the robot knows exactly when a full command has arrived, each string is terminated with a newline character (\n). This acts as a trigger for the STM32 to start processing the received data.
However, for certain tasks, two-way communication is necessary to ensure that the system stays synchronized:

– Homing procedure: The computer sends the homing command and waits for a "ready" confirmation from the board once all axes have reached their limit switches.

– IK movement: After receiving the coordinates, the STM32 notifies the computer when the movement is finished. This prevents the PC from sending new coordinates before the robot is ready for the next step.

### 7.3 Graphical User Interface (GUI)

To make the robot easy to operate, a dedicated Graphical User Interface (GUI) was developed using Python and the Tkinter library. The interface allows the user to monitor the robot’s status and choose between different control modes. At the very top, a status indicator shows whether the robot is "Ready" or "Busy" (occupied).
As shown in Figure 13, the interface is divided into several sections:
1. Inverse Kinematics (IK) Control: This section allows the user to input Cartesian coordinates (X, Y, Z) and orientation angles (Roll, Pitch, Yaw). Once the "Perform IK Move" button is pressed, the PC sends the raw data to the STM32 which calculates how to move the arm to that exact point.
2. Demo Mode: This part is used to trigger pre-programmed demonstration sequences. It is particularly useful for showing smooth TCP movements along a chosen axis without manual input.
3. Homing: The large orange button starts the homing procedure. This must be used every time the robot is powered on so that the controller can find the "zero" position for each joint using the limit switches.
4. Manual Joint Control: This section allows for the movement of each of the first five axes individually. The user can also adjust the "delay" value, which directly changes the speed of the stepper motors by increasing or decreasing the time between steps.

30

A.Pas´ | Software
5. Accessories (Servos): These sliders control the two servos located at the end of the arm. One slider rotates the sixth axis (the wrist), and the other opens or closes the gripper.
6. Vision System and Calibration: This section handles camera based control. It allows the user to start the camera, calibrate the robot’s coordinate system with the camera’s view (using ArUco markers), and enable hand tracking mode.
7. Relative Step Debugging: This is a low level tool used for testing and maintenance. It allows the user to move a specific motor by a precise number of steps in either direction.

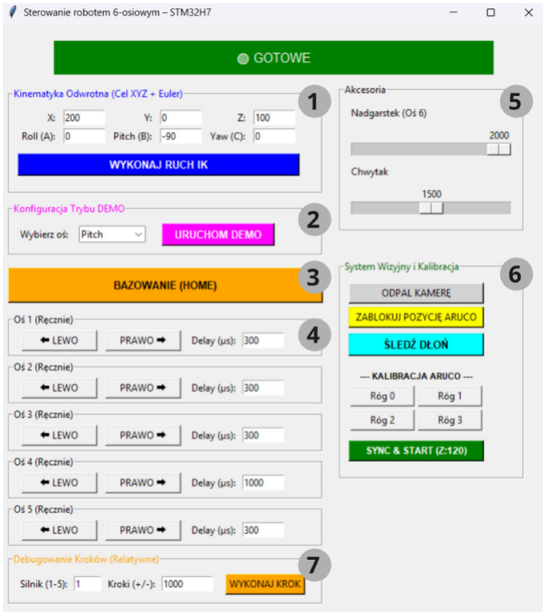
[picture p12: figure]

Figure 13. The Graphical User Interface designed for controlling the robotic arm. Source: Own work

31

Software | A.Pas´

### 7.4 Simulation and IK debugging

Before testing inverse kinematics on the physical robot, a simulation tool was created using the Matplotlib library. This tool was crucial for debugging, as it allowed a safe verification of the mathematical model. The simulation displays the robot’s pose from four different perspectives: a 3D view and three 2D projections (top, side, and front).
The user can input the coordinates (X, Y, Z) and orientation angles (Roll, Pitch, Yaw) to see how the virtual arm positions itself. At the bottom of the interface, the program displays the number of motor steps that each axis needs, to reach that position from the home state.
This function was extremely helpful during the testing. This allowed for a comparison. The coordinates were entered into the simulation and then each joint of the real robot was moved by the calculated number of steps. By checking if the real end effector ended up in the same spot as the virtual one, the accuracy of the IK algorithm could be confirmed with the reduced risk of accidental collisions.

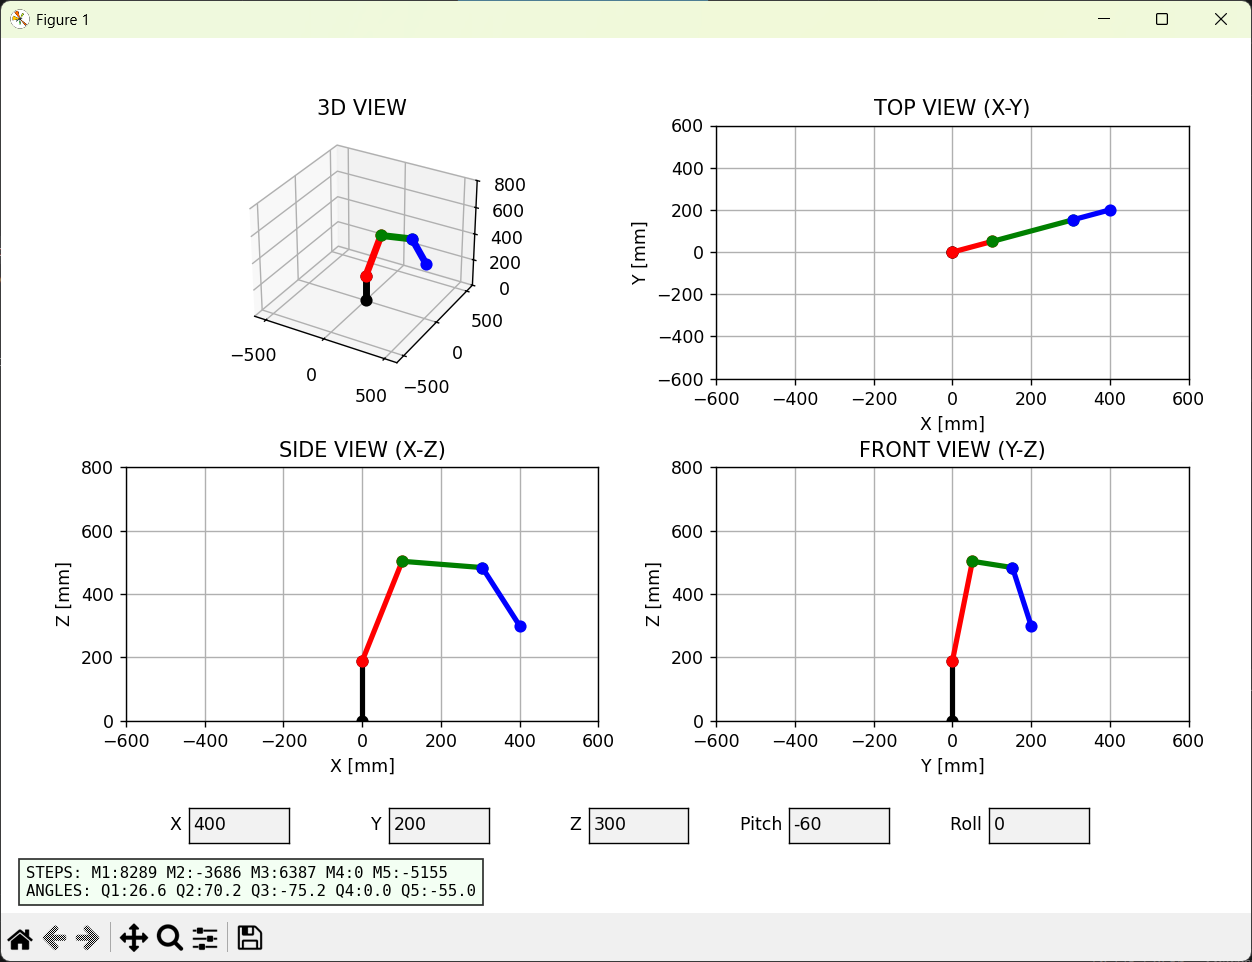
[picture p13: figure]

Figure 14. Python simulation used for Inverse Kinematics verification and debugging. Source: Own work

32

A.Pas´ | Validation and testing

## 8 Validation and testing

### 8.1 Load tests

To evaluate the physical capabilities of the robot, a series of load tests were conducted. This experiment aimed to determine the maximum payload that the arm could carry at its maximum reach. The experimental setup is shown in Figure 15.

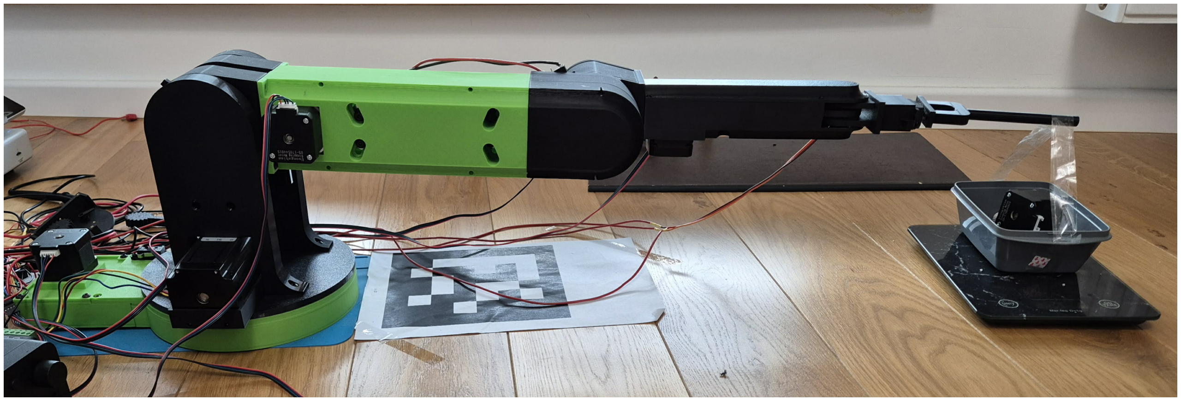
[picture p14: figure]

Figure 15. Experimental setup for measuring the robot’s lifting capacity. Source: Own work

The main bottlenecks in the robot’s lifting capacity are the second joint (shoulder) and the third joint (elbow), as they must overcome the largest torque. For this reason, the test was split into two independent tests. Each test focused on one of these joints while keeping all other axes in a locked constant position.
The tests analyzed the impact of two key variables: the microstepping ratio and the peak current supplied to the stepper motor driver.

### 8.1.1 Shoulder joint (joint 2) evaluation

In the second joint, a NEMA 23 stepper motor is used and controlled by a DM556 driver. During the test, the microstep ratio was compared between a full step (1:1) and a microstep (1:16), which corresponds to 200 and 3200 steps per revolution, respectively. In addition, two peak current limits were tested: a lower value of 2.7 A and a higher value of 4.9 A. The results of these measurements are presented in Table 8.

33

Validation and testing | A.Pas´

Table 8. Load capacity test results for Joint 2 (Shoulder).

Joint Microstepping Peak Current [A] Max Payload [g]

2 | 1:1 | 2.7 | 130
2 | 1:1 | 4.9 | 150
2 | 1:16 | 2.7 | 150
2 | 1:16 | 4.9 | 180

The payload values in the table represent the rounded average of several measurements. As expected, supplying a higher current to the motor increased its torque, allowing the arm to lift more weight. However, doubling the peak current from 2.7 A to 4.9 A resulted in only about a 15% to 20% increase in lifting capacity.
An interesting finding was the impact of microstepping. Changing the driver setting from full steps (1:1) to (1:16) microsteps increased the lifting strength by approximately 15% at 2.7 A and 20% at 4.9 A. Theoretically, increasing the microstepping ratio should decrease the holding torque because the rotor is forced to hold positions between the magnetic poles. However, in this setup, microstepping significantly reduced vibrations and jerk.
To show why this happens, the distance that the end effector moves during a single step can be calculated.

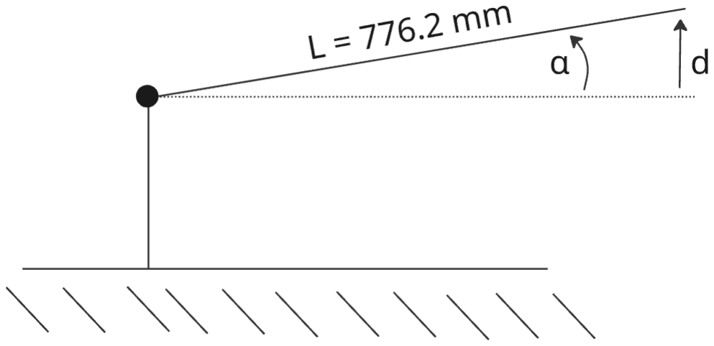
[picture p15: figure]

Figure 16. Displacement of end effector. Source: Own work

For a full step (1:1) mode, the motor rotates by α1:1 = 360◦/200 = 1.8

- per step. Assuming

a straight-line approximation for such a small angle, the displacement d1:1 of the robot’s end

34

A.Pas´ | Validation and testing

effector during a single step is:

d1:1 = L · sin(α1:1) = 776.2 mm · sin(1.8

◦
) ≈ 24.38 mm | (31)

For the (1:16) microstepping mode, the step angle is reduced to α1:16 = 360◦/3200 = 0.1125◦ per step. This results in a displacement d1:16 of:

d1:16 = L · sin(α1:16) = 776.2 mm · sin(0.1125◦
) ≈ 1.52 mm | (32)

This shows that, in full-step mode, each single step tries to move the end effector by almost 25 mm. Because the arm is 3D-printed, this sudden displacement generates huge forces, making the arm to wobble and causing the motor to fail under lighter loads than it sould. With the (1:16) microstepping ratio, the distance is just 1.5 mm, which makes the movement smoother and reduces the shaking. This allows the motor to use all its torque more efficiently.

### 8.1.2 Elbow joint (joint 3) evaluation

In the third joint, a NEMA 17 stepper motor is used and controlled by a TMC2209 driver. During the test, the microstep ratio was compared between a microstep ratio of (1:8) and (1:64), which corresponds to 1600 and 12800 steps per revolution, respectively. In addition, the reference voltage was tested from a power efficient value to the maximum, safe for the motor value [6]. The reference voltage can be calculated [13] with the equation shown below.

VREF = IRSM ·

√
2 | (33)

The results of these measurements are presented in Table 9.

Table 9. Load capacity test results for Joint 3 (Elbow).

Joint Microstepping VREF [V] IRSM [A] Max Payload [g]

3 | 1:8 | 1.0 | 0.71 | 140
3 | 1:8 | 1.4 | 0.99 | 220
3 | 1:8 | 1.8 | 1.27 | 300
3 | 1:8 | 2.2 | 1.56 | 420
3 | 1:64 | 1.0 | 0.71 | 150
3 | 1:64 | 1.4 | 0.99 | 250
3 | 1:64 | 1.8 | 1.27 | 340
3 | 1:64 | 2.2 | 1.56 | 420

The measurements show an almost linear relationship between the driver’s reference voltage and the strength of the robot, which was expected.

35

Validation and testing | A.Pas´

Similarly to the shoulder joint, increasing microstepping resulted in a slightly stronger manipulator. Moving from (1:8) to (1:64) microstepping mode improved the lifting capacity by about 7% at 1.0 V, 13% at 1.4 V, and 13% at 1.8 V.

This improvement can again be explained by analyzing the displacement at the end effector. The distance from the axis of Joint 3 (elbow) to the end of the gripper is Lelbow = 440.6 mm. For a (1:8) microstep, the joint step angle is α1:8 = 360◦/1600 = 0.225◦
. The displacement
d1:8 of the end effector during a single step is:

d1:8 = Lelbow · sin(α1:8) = 440.6 mm · sin(0.225◦
) ≈ 1.73 mm | (34)
For a (1:64) microstep, the joint step angle is α1:64 = 360◦/12800 = 0.0281◦ | , which gives

the displacement d1:64 of:

d1:64 = Lelbow · sin(α1:64) = 440.6 mm · sin(0.0281◦
) ≈ 0.22 mm | (35)

This again shows that when moving a single step, the higher value of microstepping reduces the displacement of the end effector more. That ensures smoother operation, which reduces jerk and increases strength.

### 8.2 TCP trajectory test

To evaluate path planning and joint synchronization, two Tool Center Point (TCP) trajectories, linear and semicircular, were tested and compared between the Python simulation and the physical robot.
Both movements have the same starting and ending poses. The coordinates and orientation angles for both tests are defined as follows.

– Start Pose: X = 400 mm, Y = 0 mm, Z = 0 mm, Roll = 0◦

, Pitch = −60◦ | , Yaw = 0◦

– End Pose: X = 600 mm, Y = 0 mm, Z = 0 mm, Roll = 0◦

, Pitch = −60◦ | , Yaw = 0◦

### 8.2.1 Linear trajectory

In the first test, the end effector was moved in a straight line between the start and the end point. The orientation was kept constant throughout the hole path. For the simulation, only several points were calculated to illustrate the intermediate poses, but for the movement of the physical robot, the entire path was split into small steps to keep the desired path throughout the entire distance.
The following is a comparison of the trajectory generated in the simulation and the actual physical movement of the robotic arm.

36

A.Pas´ | Validation and testing

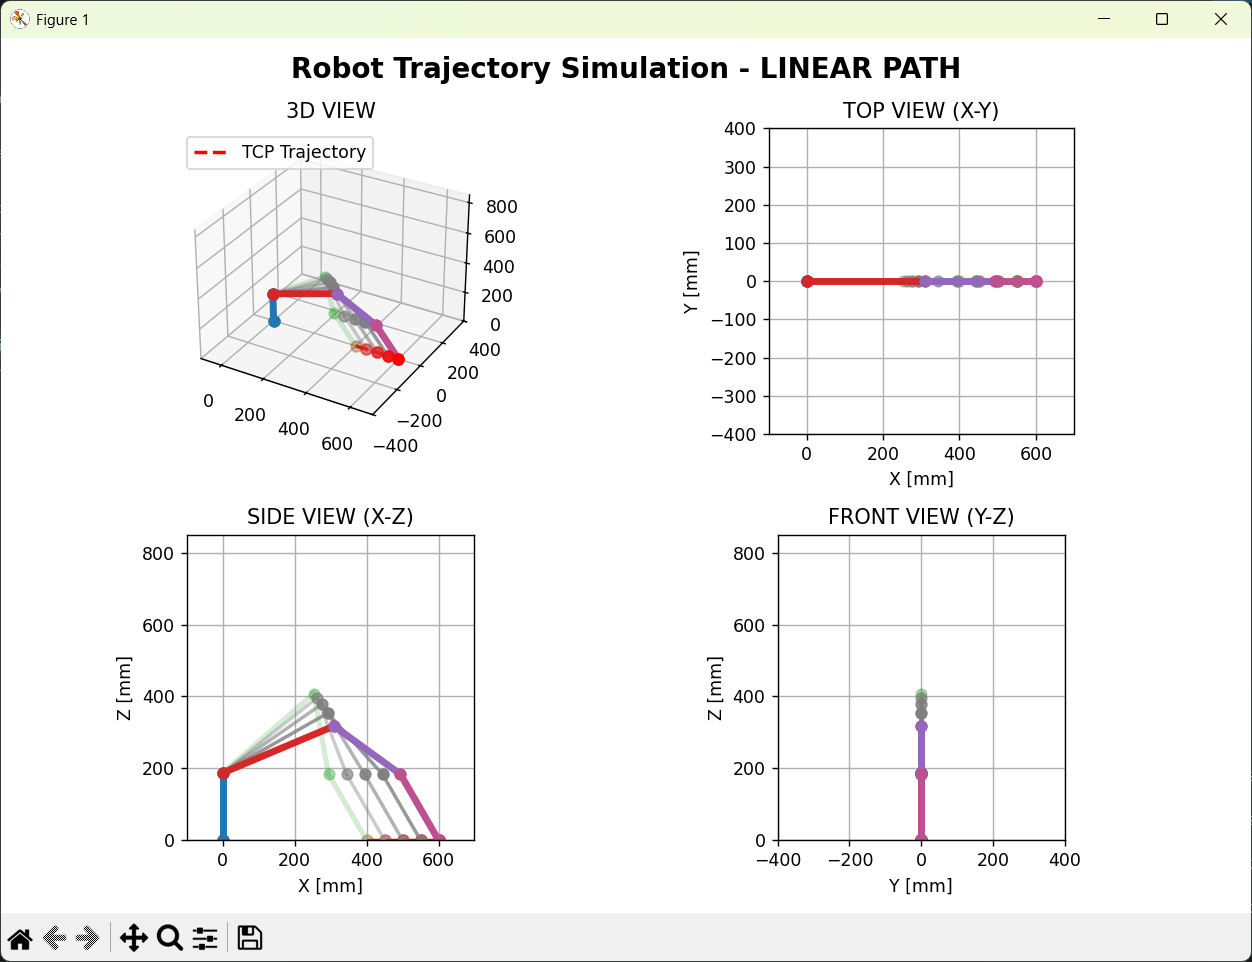
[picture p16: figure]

Figure 17. Python simulation showing the poses of the robotic arm during the linear trajectory. Source: Own work

37

Validation and testing | A.Pas´

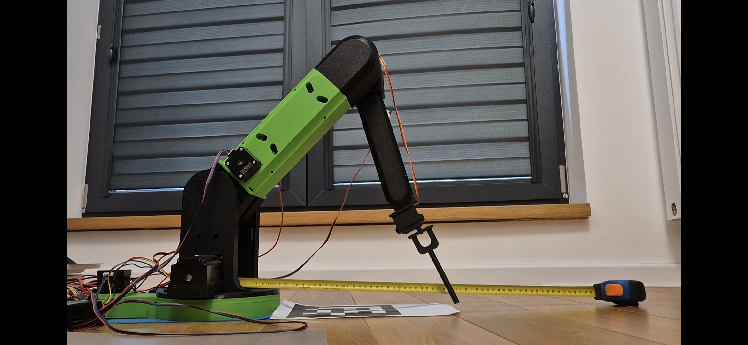
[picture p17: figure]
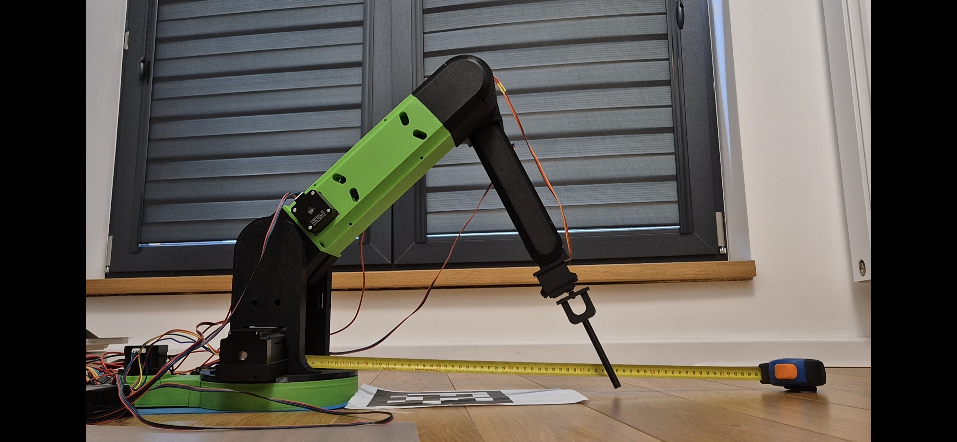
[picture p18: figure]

(a) Position 1 (Start) | (b) Position 2
(c) Position 3 | (d) Position 4

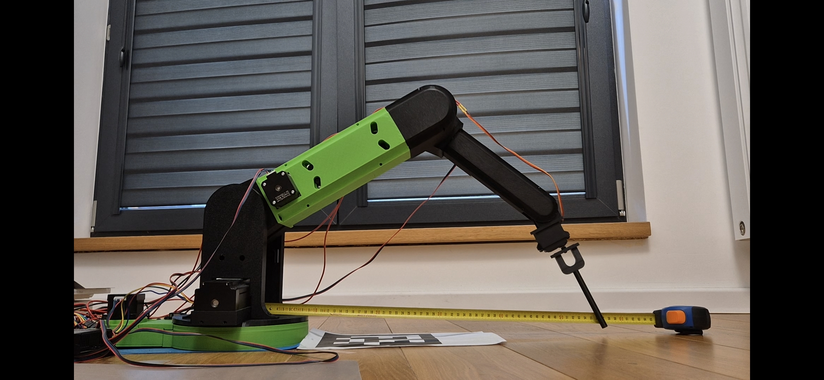
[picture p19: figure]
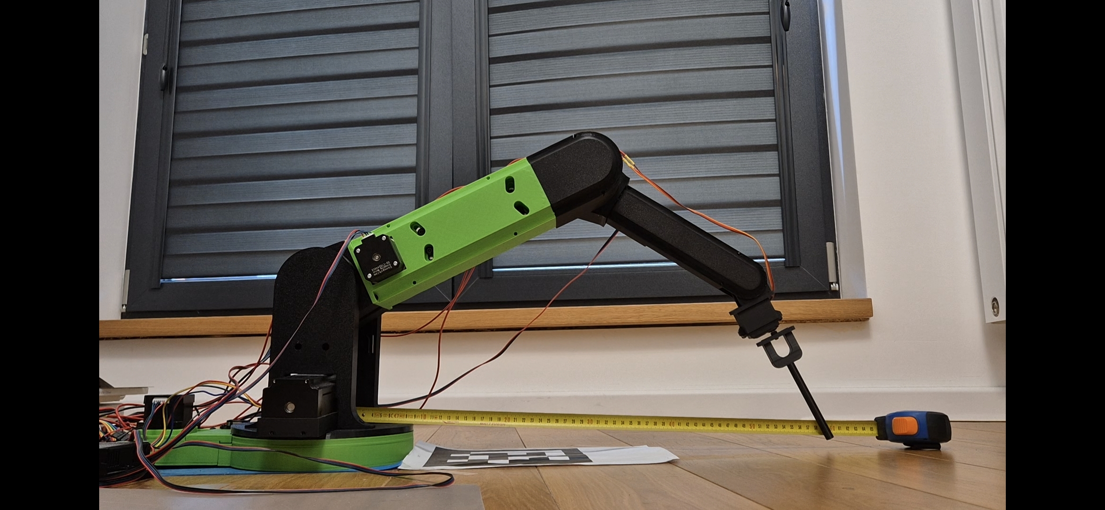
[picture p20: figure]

(e) Position 5 | (f) Position 6 (End)

Figure 18. Steps of the physical robotic arm executing the linear trajectory. Source: Own work

### 8.2.2 Semicircular trajectory

In the second test, the end effector was moved in a semicircular arc between the same coordinates. Again, the orientation was kept constant. Simulation shows several possible configurations in the trajectory while the physical robot traveled the entire path. This test was crucial in verifying how well the system coordinates multiple axes.
The following is a comparison of the trajectory generated in the simulation and the actual physical movement of the robotic arm.

38

A.Pas´ | Validation and testing

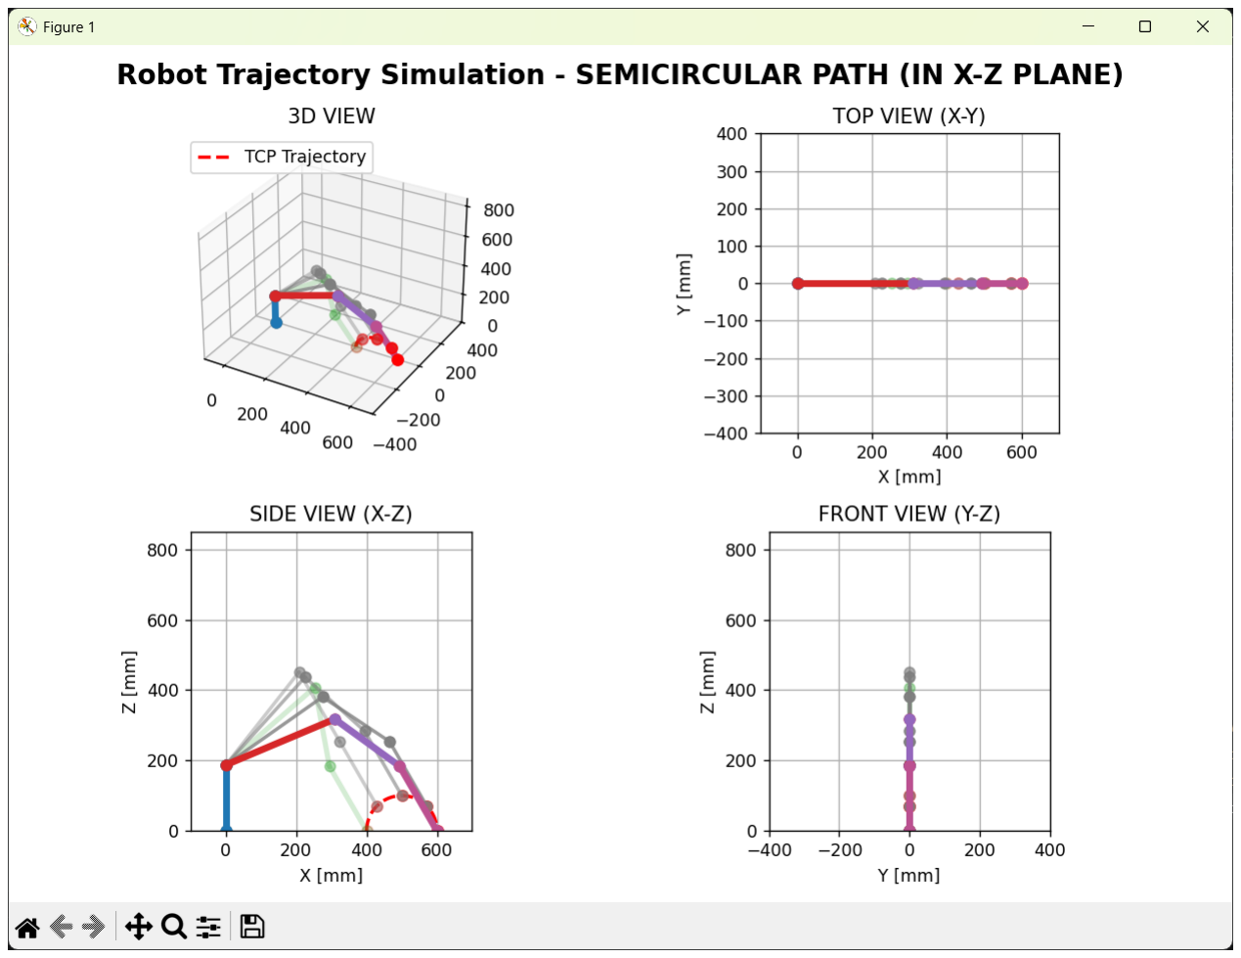
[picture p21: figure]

Figure 19. Python simulation showing the sequential poses of the robotic arm during the semicircular trajectory. Source: Own work

39

Validation and testing | A.Pas´

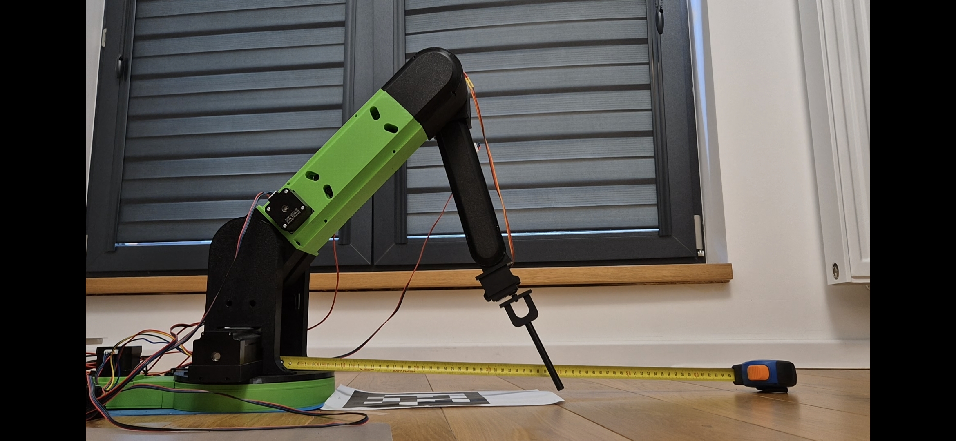
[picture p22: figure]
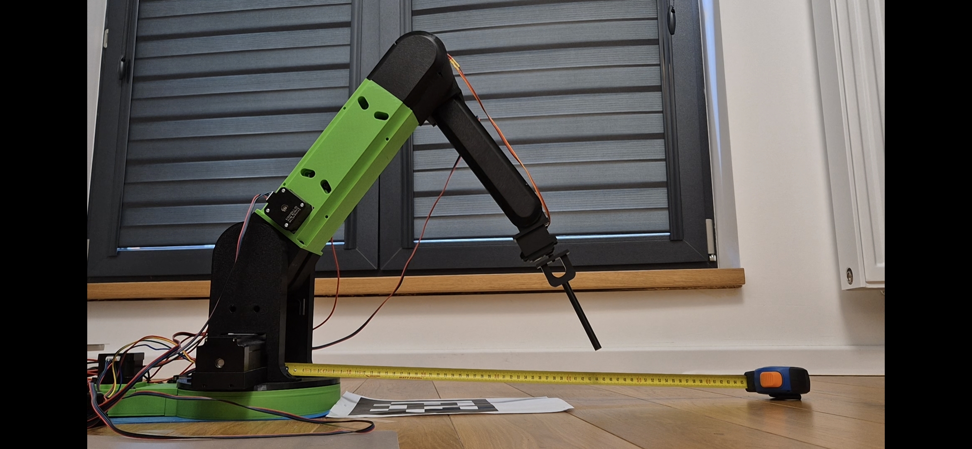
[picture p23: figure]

(a) Position 1 (Start) | (b) Position 2
(c) Position 3 | (d) Position 4

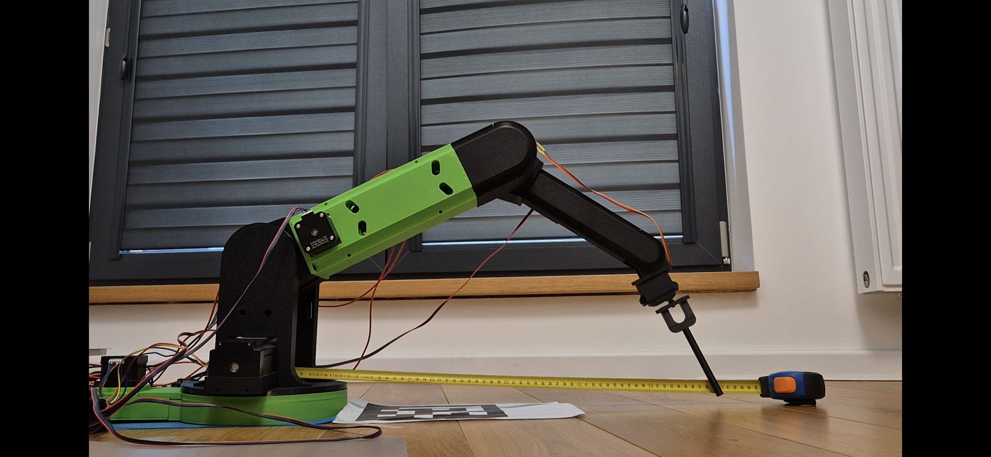
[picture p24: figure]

(e) Position 5 | (f) Position 6 (End)

Figure 20. Steps of the physical robotic arm executing the semicircular trajectory. Source: Own work

### 8.2.3 Trajectory Exceptions

As mentioned in Section 6.3, a single pose can be achieved using 8 different sets of solutions. A prime example of this is the "Elbow Up" and "Elbow Down" configuration. In that case, the second (arm) and third (forearm) joints are mirrored downward. Consequently, the coordinates and orientation remain exactly the same in both cases, but the joint configurations are different. To avoid this ambiguity, a software function prioritizing a single solution was implemented, taking into account the constraints of the robot’s physical movements.

40

A.Pas´ | Conclusions

## 9 Conclusions

This thesis showed that it is entirely feasible to design and construct a 6cDof robotic arm using mainly 3D printed parts. The manipulator uses the same kinematics and similar control logic as those found in industrial robots. Due to its lightweight plastic construction, the arm is safe for human interaction, making it a great tool for cooperation, learning, and further experimentation.

### 9.1 Summary of results

The performance of the robotic arm was evaluated with two experiments, load testing and trajectory verification.
The load tests gave interesting results. Although theoretical models say that full step control gives a holding torque higher than that of microstepping, practical tests proved otherwise. Because full steps produce greater displacement of the end effector, they generate vibrations. In contrast, microstepping provided smoother motion, which prevents the motor from stalling and allowing it to lift higher payloads.
Another interesting finding is the difference between the theoretical maximum strength and the experimental limits. When comparing the torque requirements calculated in Chapter 4.3 with the theoretical torque presented in table 5, one could see that the system should have a large reserve of strength. However, tests showed that a real world model needs to take into account mechanical wear and component flexibility. Since 3D-printed parts are not 100% rigid, a minor flex appears under load, creating additional moments, which decreases the final manipulators strength.
The second test focused on trajectory tracking, where the manipulator performed exceptionally well. The software managed to handle real time inverse kinematics and velocity scaling, allowing the arm to calculate and execute commands without any visible latency. The paths executed by the robot match the trajectories generated in the Python simulation with a margin of backlash error.

### 9.2 Evaluation of potential usage in real life applicaiton

Based on the experimental results, the robotic arm is perfect for educational and research purposes for schools and universities. It could serve as a tool for teaching future engineers everything regarding robotics, including:

– CAD modeling for modular upgrades and maintenance

– selection of electronic components such as motors, drivers, microcontrollers

– Mathematical models such as forwars and inverse kinematics

| 41

Conclusions | A.Pas´

– programming the microcontroller, communication, and trajectory planning;

The fact that the manipulator has limited payload is not a drawback. The robot was not designed to lift heavy industrial loads, but rather to work with lightweight tools or execute precise operations (such as moving small objects or demonstrating sorting algorithms). In fact, this lower payload and light weight increases safety, ensuring that programming errors made by students will not result in equipment damage or personal injury.

### 9.3 Future improvements

Although the robotic arm is fully functional, this is the first version, and it should receive future improvements. The crucial software upgrade is adding a vision system for closed loop control. With a camera and machine learning algorithms, the robot could correct its movements, detect objects, and pick the chosen items.
Another interesting improvement would be constructing a second manipulator for multi robot cooperation and collision avoidance within a shared workspace while executing the desired task.
In addition, some improvements are necessary for the current design. The temporary breadboard circuits should be replaced with a Printed Circuit Board (PCB) to ensure that hardware is not an issue when tackling on a hard task. Another things are cables. Hiding them inside the 3D-printed case would eliminate the risk of tangling and make the whole build look cleaner. Finally, the precision of the Tool Center Point could be improved with the mechanical tolerances of the 3D-printed gear to minimize backlash.

42

A.Pas´ | REFERENCES

## References

[1] Robotnik. History of robots and robotics | origins of robots, 2021. URL https://ro

botnik.eu/history-of-robots-and-robotics/. (https://robotnik.eu/history-of-robots-and-robotics/) Accessed: 2026-01-26.

[2] scioly. Robot arm, 2025. URL https://scioly.org/wiki/Robot_Arm. Accessed: 2026-06-16.
[3] FANUC. Fanuc - world market leader in factory automation. https://www.fanuc.

eu/pl-pl/produkt/robot/m-1000ia. (https://www.fanuc.eu/pl-pl/produkt/robot/m-1000ia) Accessed: 2026-01-30.

[4] ASTOR. Astor - sklep internetowy. https://www.astor.com.pl/sklep/robot

yzacja/robot-edukacyjny-astorino/astorino-basic-b002.html, (https://www.astor.com.pl/sklep/robotyzacja/robot-edukacyjny-astorino/astorino-basic-b002.html) 2025. Accessed: 2026-03-17.

[5] Chris Annin. | Learn robotics with arduino and the ar4 diy robot arm. | https:

//anninrobotics.com/learn-robotics-with-arduino-and-the-ar

4-diy-robot-arm/?srsltid=AfmBOoojhTjv1I_OnwyaGcLue_-pt6pgk

l9J_9YhnjPoUnE2FqKPJyxb/. (https://anninrobotics.com/learn-robotics-with-arduino-and-the-ar4-diy-robot-arm/) Accessed: 2026-01-30.

[6] alldatasheet.pl. Nema17 pdf, 2020. URL https://www.alldatasheet.com/d

atasheet-pdf/view/2268109/MOTIONKING/17HS4401S.html. (https://www.alldatasheet.com/datasheet-pdf/view/2268109/MOTIONKING/17HS4401S.html) Accessed: 2026-03-17.

[7] luna.co. Nema23 pdf, 2020. URL https://luna.co.in/wp-content/upload

s/2019/12/nema23-57HS-2-phase-1.8%C2%B0.pdf. (https://luna.co.in/wp-content/uploads/2019/12/nema23-57HS-2-phase-1.8%C2%B0.pdf) Accessed: 2026-03-17.

[8] Markforged. | 3d printing settings impacting part strength, 2025. | URL

https://markforged.com/resources/learn/design-for-additi

ve-manufacturing-plastics-composites/understanding-3d-print

ing-strength/3d-printing-settings-impacting-part-strength. (https://markforged.com/resources/learn/design-for-additive-manufacturing-plastics-composites/understanding-3d-printing-strength/3d-printing-settings-impacting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) Accessed: 2026-04-02.

[9] digikey.com. Nema17 pdf, 2020. URL https://www.digikey.com/en/produ

cts/detail/olimex-ltd/SM-17HS4023/21662354. (https://www.digikey.com/en/products/detail/olimex-ltd/SM-17HS4023/21662354) Accessed: 2026-03-17.

[10] electronicoscaldas.com. sg995 pdf, 2020. URL https://www.electronicoscald

as.com/datasheet/MG995_Tower-Pro.pdf. (https://www.electronicoscaldas.com/datasheet/MG995_Tower-Pro.pdf) Accessed: 2026-03-17.

[11] STMicroelectronics. Stm32 h755zi-q, 2020. URL https://www.st.com/en/eval

uation-tools/nucleo-h755zi-q.html. (https://www.st.com/en/evaluation-tools/nucleo-h755zi-q.html) Accessed: 2026-03-17.

43

REFERENCES | A.Pas´
[12] Carlos Ross. Systems and robotics — course resources, 2024. URL https://biomechatronics.ca/teaching/sr/. (https://biomechatronics.ca/teaching/sr/) Associate Professor, P.Eng.; Ph.D. (Sorbonne Université, UPMC). Accessed: 2026-01-07.
[13] circuitist. How to set your stepper driver current: A4988, drv8825, tmc2208, tmc2209,

2022. URL https://www.circuitist.com/how-to-set-driver-curre

nt-a4988-drv8825-tmc2208-tmc2209/. (https://www.circuitist.com/how-to-set-driver-current-a4988-drv8825-tmc2208-tmc2209/) Accessed: 2026-04-29.

44

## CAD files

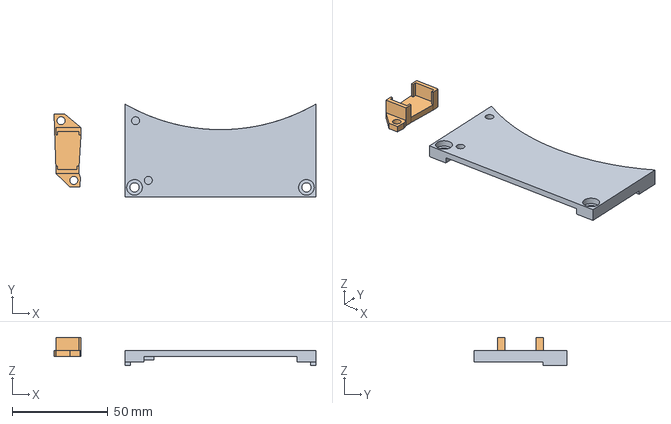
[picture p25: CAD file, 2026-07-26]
3d_models/1_os_podstawa/gora_podstawy_nakladka.FCStd
137.1 x 48.6 x 14.9 mm
nakladka
krancowka

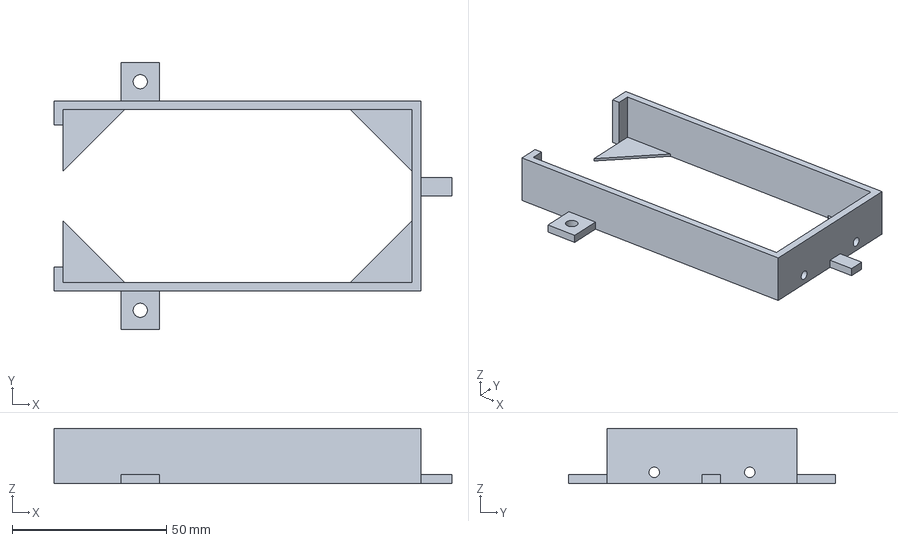
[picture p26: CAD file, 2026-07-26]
3d_models/2_os/trzymacz_silnika_2_os.FCStd
129.2 x 86.6 x 18.0 mm

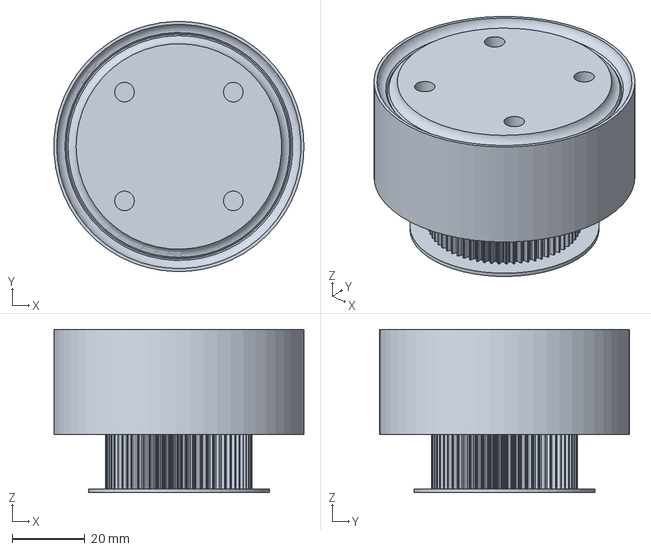
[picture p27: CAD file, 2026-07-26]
3d_models/3_os_ramie/trzecia_os_zebatka_64.FCStd
68.9 x 69.0 x 45.0 mm

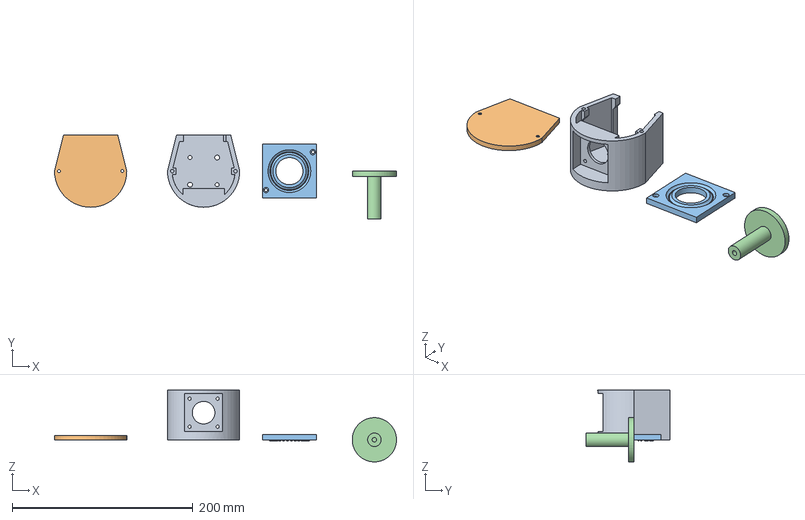
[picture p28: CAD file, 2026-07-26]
3d_models/4_os_przedramie/lokiec_przejscie_2_ramie.FCStd
378.5 x 93.0 x 79.5 mm
przejscie_lokiec
nakladka
przejscie_lokiec_przedramie
na_wal_silnika

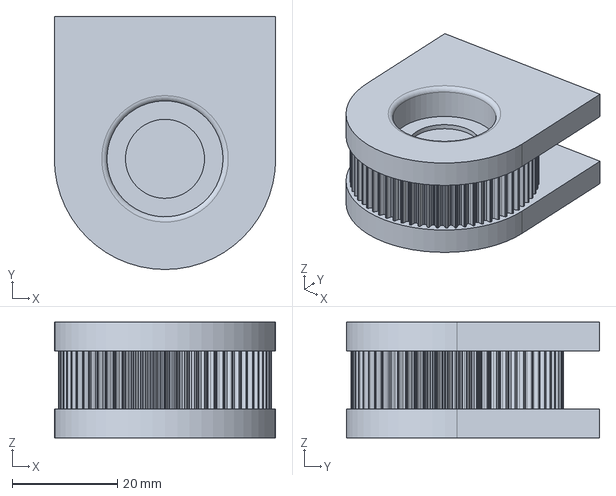
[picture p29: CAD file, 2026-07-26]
3d_models/5_os_nadgarstek/os_5_zebatka_64.FCStd
42.0 x 48.0 x 22.0 mm

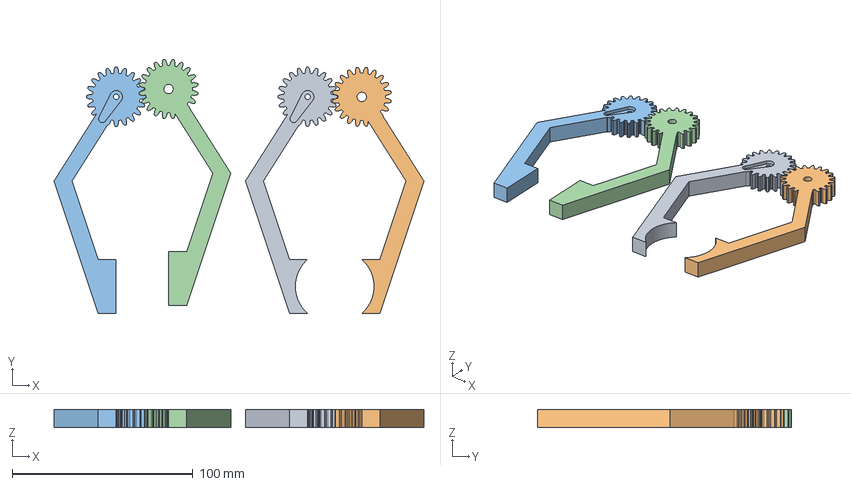
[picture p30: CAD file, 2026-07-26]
3d_models/6_os_dlon/zebatki_chwytak.FCStd
204.9 x 140.7 x 10.0 mm
zebatka_serwo
zebatka_pusta
zebatka_serwo_plaskie
zebatka_pusta_plaskie

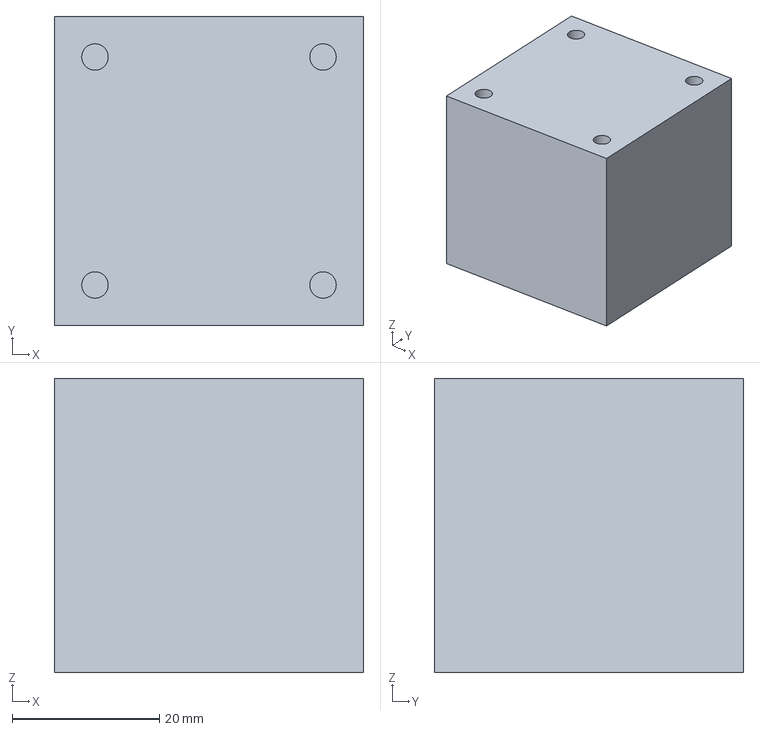
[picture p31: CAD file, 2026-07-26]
3d_models/do_zlozenia/silnik.FCStd
42.0 x 42.0 x 40.0 mm

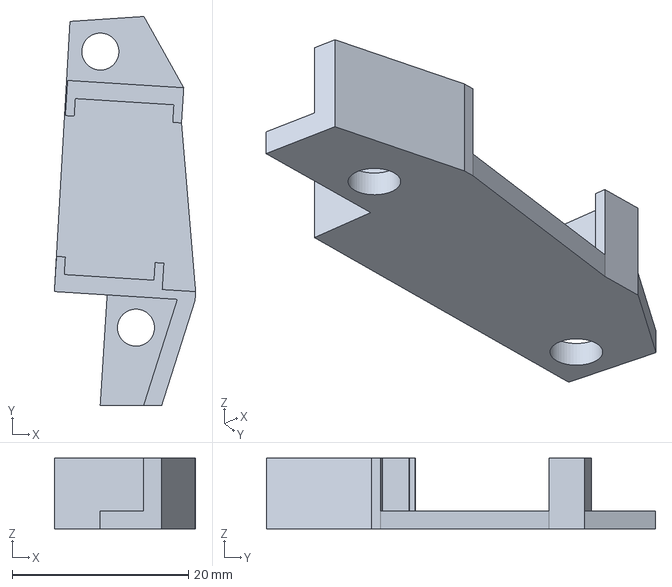
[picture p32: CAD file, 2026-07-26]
3d_models/krancowka_wzor.FCStd
16.0 x 44.1 x 8.00 mm

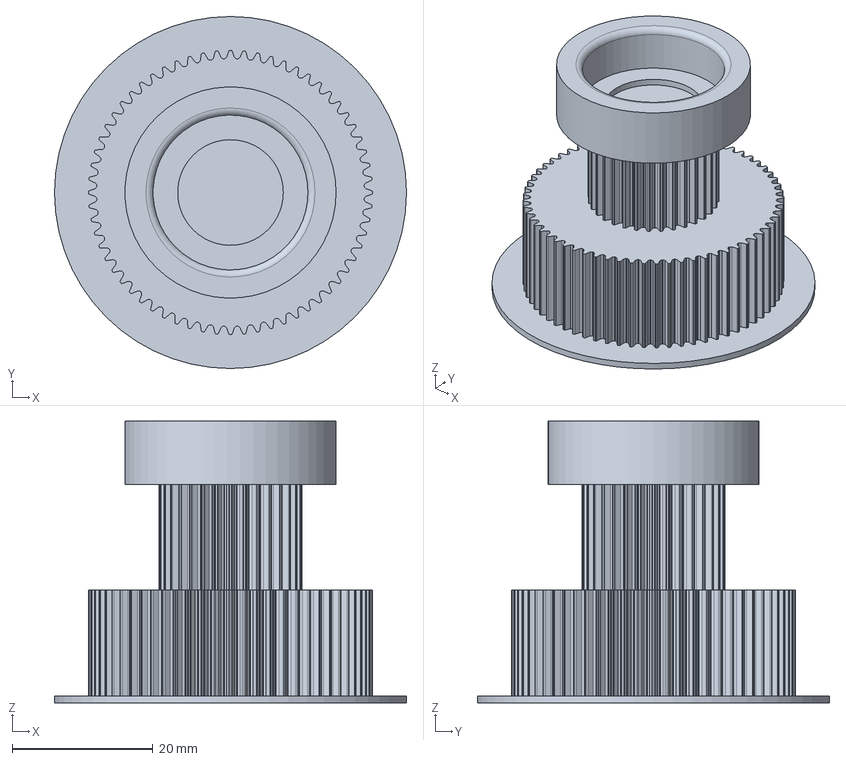
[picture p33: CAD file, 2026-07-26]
3d_models/zebatki/zebatka_64_32.FCStd
50.0 x 50.0 x 40.0 mm

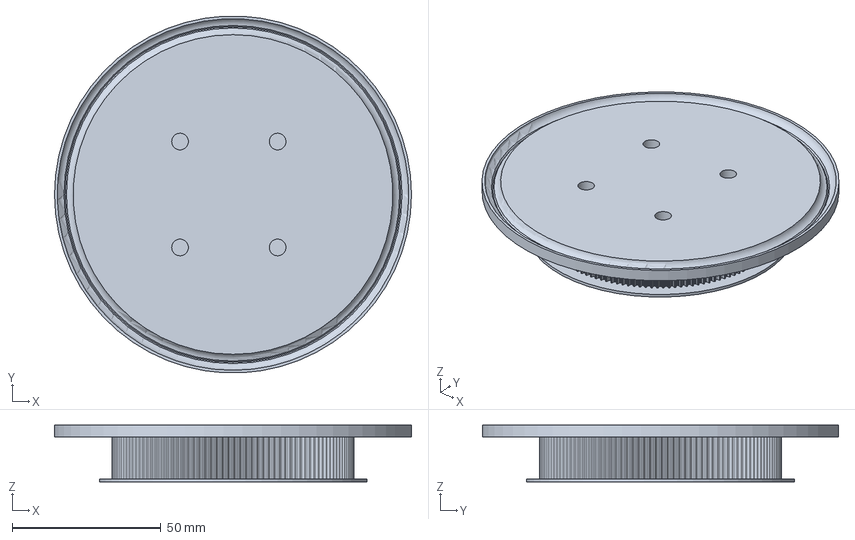
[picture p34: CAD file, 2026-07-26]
3d_models/1_os_podstawa/zebatka_128_pierwsza_os_duza.FCStd
120.0 x 119.8 x 19.0 mm

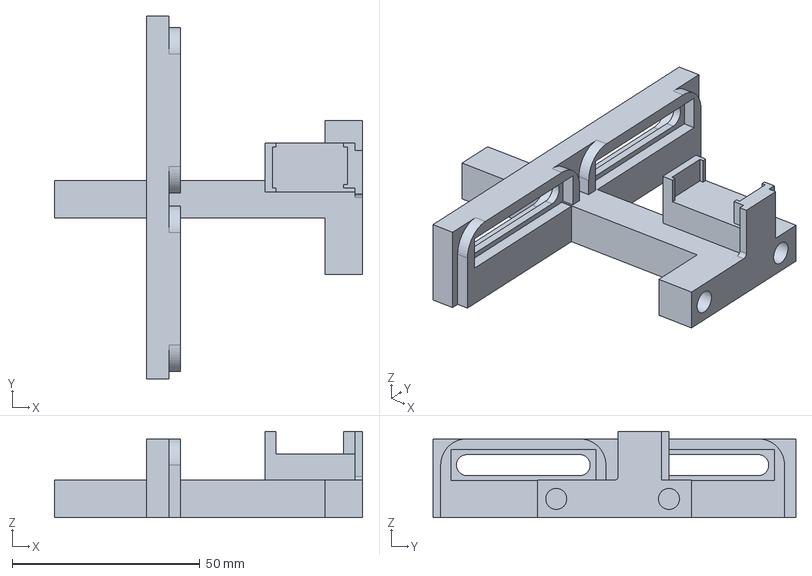
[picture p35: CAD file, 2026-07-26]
3d_models/2_os/laczenie_stojakow_druga_os.FCStd
82.0 x 96.6 x 23.0 mm

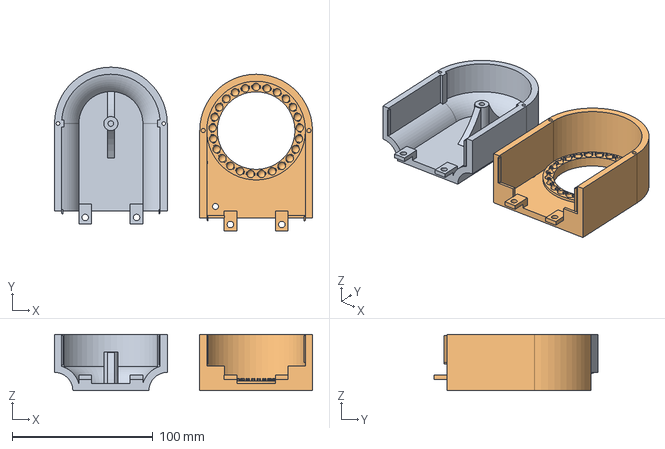
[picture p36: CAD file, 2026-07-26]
3d_models/3_os_ramie/lokiec_3_os.FCStd
183.0 x 116.1 x 40.0 mm
lokiec_silnik
lokiec_lacznik

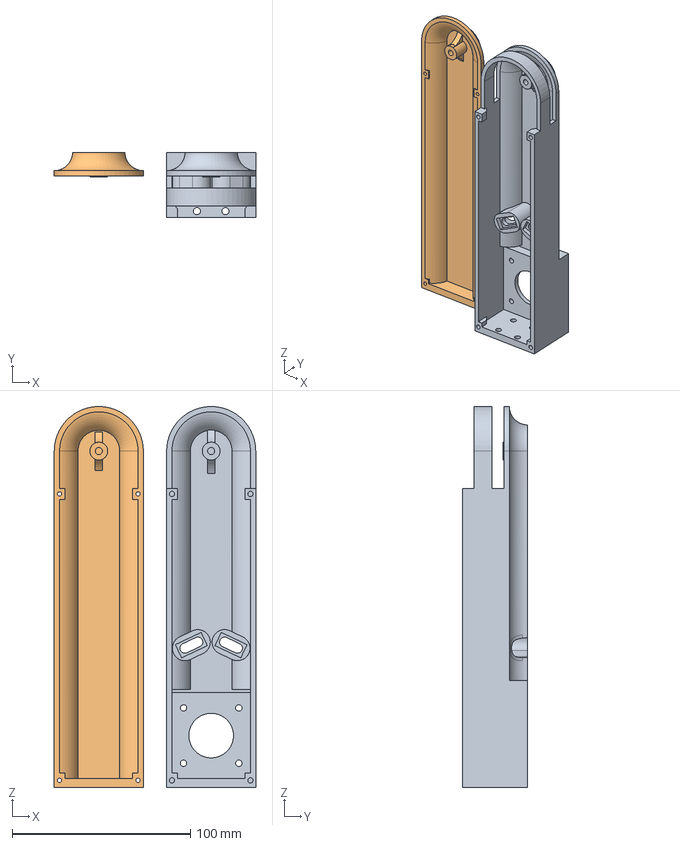
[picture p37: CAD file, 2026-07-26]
3d_models/4_os_przedramie/przedramie.FCStd
113.0 x 36.7 x 213.6 mm
silnik
czysta_strona_3mm

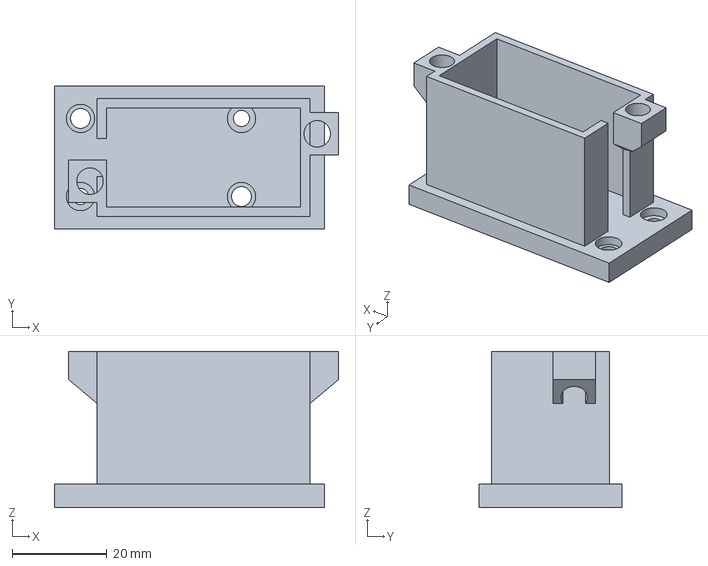
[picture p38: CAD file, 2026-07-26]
3d_models/6_os_dlon/trzymacz_6_osi.FCStd
60.0 x 30.2 x 33.0 mm

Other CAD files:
3d_models/do_zlozenia/lozysko_8_22_7.FCStd
3d_models/pogladowe_zlozenie.FCStd
3d_models/zebatki/zebatka_128.FCStd
3d_models/1_os_podstawa/gora_podstawy_silnik.FCStd
3d_models/1_os_podstawa/gora_obrotowa.FCStd
3d_models/1_os_podstawa/gora_podstawy_nie_obrotowa.FCStd
3d_models/1_os_podstawa/podstawa_duza.FCStd
3d_models/1_os_podstawa/podstawa_silnik_dol.FCStd
3d_models/2_os/druga_os_zebatka_wieksza_dziura.FCStd
3d_models/2_os/slupek_lozysko.FCStd
3d_models/2_os/stojaki_trzymajace_druga_os.FCStd
3d_models/3_os_ramie/pierwsze_ramie.FCStd
3d_models/6_os_dlon/chwytak_koniec.FCStd
3d_models/6_os_dlon/wskaznik.FCStd
3d_models/pogladowe_zlozenie.stl
3d_models/zebatki/zebatka_32.FCStd
3d_models/zebatki/zebatka_64.FCStd

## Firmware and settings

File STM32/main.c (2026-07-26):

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
/* Includes ------------------------------------------------------------------*/
#include "main.h"

/* USER CODE BEGIN Includes */
#include <stdlib.h>
#include <stdio.h>
#include <string.h>
/* USER CODE END Includes */

/* USER CODE BEGIN PD */

/* DUAL_CORE_BOOT_SYNC_SEQUENCE: Define for dual core boot synchronization    */
/*                             demonstration code based on hardware semaphore */
/* This define is present in both CM7/CM4 projects                            */
/* To comment when developping/debugging on a single core                     */
//#define DUAL_CORE_BOOT_SYNC_SEQUENCE
//
//#if defined(DUAL_CORE_BOOT_SYNC_SEQUENCE)
//#ifndef HSEM_ID_0
//#define HSEM_ID_0 (0U) /* HW semaphore 0*/
//#endif
//#endif /* DUAL_CORE_BOOT_SYNC_SEQUENCE */

/* USER CODE END PD */


TIM_HandleTypeDef htim2;
TIM_HandleTypeDef htim3;
TIM_HandleTypeDef htim6;

UART_HandleTypeDef huart3;

/* USER CODE BEGIN PV */
typedef struct {
    GPIO_TypeDef* stepPort; uint16_t stepPin;
    GPIO_TypeDef* dirPort;  uint16_t dirPin;
    GPIO_TypeDef* limitPort; uint16_t limitPin;

    uint32_t currentDelay;
    uint32_t configTargetDelay;
    uint32_t targetDelay;
    uint32_t maxDelay;

    int8_t direction;
    uint32_t lastStep;
    uint32_t lastAccelUpdate;
    uint8_t isHoming;

    int32_t stepsToMove;
    int32_t totalStepsToMove;
    int32_t currentPos;
    float currentPosFloat;
} Stepper;

Stepper motors[5];
uint8_t rx_buffer[128];
uint8_t rx_data;
int rx_index = 0;

uint8_t homing_active = 0;

uint8_t ik_active = 0;

#define PI 3.14159265358979323846f

// Kąty w jakich znajdują się osie w momencie uderzenia w krańcówkę (w stopniach)
float home_angles[5] = {-90.0f, 135.5f, -168.0f, 0.0f, 90.0f};

// Długości ramion (przykładowe w mm)
float a2 = 335.6f;
float a3 = 228.6f;
float d1 = 187.3f;
float d6 = 212.0f;

// Aktualna i docelowa pozycja kątowa (w radianach)
float current_theta[6] = {0,0,0,0,0,0};
float target_theta[6] = {0,0,0,0,0,0};

// Przeliczniki
// Używam przełożenia 1/16 mikrokroków czyli 3200 kroków na obrót.
// Ale dodatkowo osie mają przełożenia ilość obrotów silnika do obrotu osi. Oś 1 ma 1/8, oś 2. ma 20/128, oś 3 ma 1/8, oś 4 ma 1/1, oś 5 ma 1/4.
// Oś 6 jest to serwo mg995 więc tutaj trzeba będzie dodać jakieś uproszczone założenia, bo ono ma ruch tylko 0-180 stopni
// Wartości są *2 bo mam toggle pin więc co drugi imppuls daje impuls dodatni, a co za tym idzie krok.
float steps_per_deg[5] = {-71.1111f * 2, 56.8889f * 2, -71.1111f * 2, 8.8889f * 2, 35.5556f * 2};
float current_angles[6] = {0,0,0,0,0,0}; // w stopniach

uint8_t demo_mode = 0;
int8_t demo_direction = 1;
char demo_type = 'P';

// Stałe bezpieczne zakresy
float demo_min = -80.0f;
float demo_max = 0.0f;
float demo_step = 0.5f;
float demo_current_val = -60.0f;

// Stały punkt bazowy dla Demo
const float DEMO_BASE_X = 300.0f;
const float DEMO_BASE_Y = 0.0f;
const float DEMO_BASE_Z = 300.0f;
const float DEMO_BASE_P = -60.0f;

#define MOVE_BUFFER_SIZE 16 // Bufor na 16 odcinków drogi

typedef struct {
    int32_t steps[5];
    uint32_t targetDelays[5]; // Indywidualne prędkości dla tego segmentu
    uint8_t active;
} MoveSegment;

MoveSegment moveBuffer[MOVE_BUFFER_SIZE];
volatile int bufferReadIdx = 0;  // Gdzie jest aktualnie robot
volatile int bufferWriteIdx = 0; // Gdzie Python dodaje nowe punkty

volatile uint8_t command_ready = 0;

volatile uint32_t current_max_ramp = 400;
/* USER CODE END PV */

void SystemClock_Config(void);
static void MX_GPIO_Init(void);
static void MX_TIM2_Init(void);
static void MX_TIM3_Init(void);
static void MX_USART3_UART_Init(void);
static void MX_TIM6_Init(void);
/* USER CODE BEGIN PFP */
void init_motors(void);
void update_speed(int id);
void compute_IK(float tx, float ty, float tz, float pitch_d, float roll_d);
void move_to_angles();
void load_next_segment();
void add_to_buffer(int32_t steps[5], uint32_t targets[5]);
void process_command(char* cmd);
/* USER CODE END PFP */

/* USER CODE BEGIN 0 */
#ifdef __GNUC__
#define PUTCHAR_PROTOTYPE int __io_putchar(int ch)
#else
#define PUTCHAR_PROTOTYPE int fputc(int ch, FILE *f)
#endif

PUTCHAR_PROTOTYPE {
  HAL_UART_Transmit(&huart3, (uint8_t *)&ch, 1, HAL_MAX_DELAY);
  return ch;
}
/* USER CODE END 0 */

/**
  * @brief  The application entry point.
  * @retval int
  */
int main(void)
{

/* USER CODE BEGIN Boot_Mode_Sequence_0 */
#if defined(DUAL_CORE_BOOT_SYNC_SEQUENCE)
  int32_t timeout;
#endif /* DUAL_CORE_BOOT_SYNC_SEQUENCE */
/* USER CODE END Boot_Mode_Sequence_0 */

/* USER CODE BEGIN Boot_Mode_Sequence_1 */
#if defined(DUAL_CORE_BOOT_SYNC_SEQUENCE)
  /* Wait until CPU2 boots and enters in stop mode or timeout*/
  timeout = 0xFFFF;
  while((__HAL_RCC_GET_FLAG(RCC_FLAG_D2CKRDY) != RESET) && (timeout-- > 0));
  if ( timeout < 0 )
  {
  Error_Handler();
  }
#endif /* DUAL_CORE_BOOT_SYNC_SEQUENCE */
/* USER CODE END Boot_Mode_Sequence_1 */
  /* MCU Configuration--------------------------------------------------------*/

  /* Reset of all peripherals, Initializes the Flash interface and the Systick. */
  HAL_Init();

  /* Configure the system clock */
  SystemClock_Config();
/* USER CODE BEGIN Boot_Mode_Sequence_2 */
#if defined(DUAL_CORE_BOOT_SYNC_SEQUENCE)
/* When system initialization is finished, Cortex-M7 will release Cortex-M4 by means of
HSEM notification */
/*HW semaphore Clock enable*/
__HAL_RCC_HSEM_CLK_ENABLE();
/*Take HSEM */
HAL_HSEM_FastTake(HSEM_ID_0);
/*Release HSEM in order to notify the CPU2(CM4)*/
HAL_HSEM_Release(HSEM_ID_0,0);
/* wait until CPU2 wakes up from stop mode */
timeout = 0xFFFF;
while((__HAL_RCC_GET_FLAG(RCC_FLAG_D2CKRDY) == RESET) && (timeout-- > 0));
if ( timeout < 0 )
{
Error_Handler();
}
#endif /* DUAL_CORE_BOOT_SYNC_SEQUENCE */
/* USER CODE END Boot_Mode_Sequence_2 */

  /* Initialize all configured peripherals */
  MX_GPIO_Init();
  MX_TIM2_Init();
  MX_TIM3_Init();
  MX_USART3_UART_Init();
  MX_TIM6_Init();
  /* USER CODE BEGIN 2 */
    init_motors();
	HAL_TIM_PWM_Start(&htim2, TIM_CHANNEL_1);  // Serwo 1
	HAL_TIM_PWM_Start(&htim3, TIM_CHANNEL_1);  // Serwo 2
	HAL_UART_Receive_IT(&huart3, &rx_data, 1); // Start nasłuchu UART
	HAL_TIM_Base_Start_IT(&htim6);
  /* USER CODE END 2 */

  /* Infinite loop */
  /* USER CODE BEGIN WHILE */
	while (1)
	{
		uint8_t any_axis_still_homing = 0;

		if (command_ready) {
		    process_command((char*)rx_buffer);
		    command_ready = 0;
		}

		for (int i = 0; i < 5; i++) {
			// 1. Zawsze aktualizujemy rampę (prędkość)
			update_speed(i);

			// 2. Logika krańcówek (Hard Stop)
			if (motors[i].direction != 0) {
				if (motors[i].limitPort != NULL && HAL_GPIO_ReadPin(motors[i].limitPort, motors[i].limitPin) == GPIO_PIN_SET) {
					if (motors[i].direction == 1) { // Blokujemy tylko jazdę w stronę krańcówki
						motors[i].direction = 0;
						motors[i].stepsToMove = 0; // Kasujemy zadanie ruchu
						motors[i].totalStepsToMove = 0;
						motors[i].currentDelay = motors[i].maxDelay;
						if (motors[i].isHoming) {
							motors[i].isHoming = 0;
							float home_pos = home_angles[i] * steps_per_deg[i];
							motors[i].currentPos = (int32_t)home_pos;
							motors[i].currentPosFloat = home_pos;
						}
					}
				}
			}
			if (i < 3 && motors[i].isHoming) any_axis_still_homing = 1;
		}

		if (homing_active && !any_axis_still_homing) {
			for(int i = 0; i < 5; i++) {
				// Obliczamy precyzyjną pozycję startową na podstawie kątów bazowych
				float home_steps_float = home_angles[i] * steps_per_deg[i];
				// Synchronizujemy obie zmienne
				motors[i].currentPosFloat = home_steps_float;
				motors[i].currentPos = (int32_t)roundf(home_steps_float);
				// Na wszelki wypadek czyścimy zadania ruchu
				motors[i].stepsToMove = 0;
				motors[i].direction = 0;
				motors[i].targetDelay = motors[i].configTargetDelay;
			}
			printf("HOMING_DONE\r\n");
			homing_active = 0;
		}

		int buffer_usage = (bufferWriteIdx - bufferReadIdx + MOVE_BUFFER_SIZE) % MOVE_BUFFER_SIZE;
		if (ik_active && buffer_usage < (MOVE_BUFFER_SIZE - 5)) {
			printf("IK_DONE\r\n");
			ik_active = 0;
		}

		// --- SEKCJA LOGIKI TRYBU DEMO W WHILE(1) ---
		if (demo_mode && !ik_active) {

			// 1. Aktualizacja wartości oscylującej
			demo_current_val += demo_step * demo_direction;

			// 2. Odbicie od limitów
			if (demo_current_val >= demo_max) {
				demo_current_val = demo_max;
				demo_direction = -1;
			} else if (demo_current_val <= demo_min) {
				demo_current_val = demo_min;
				demo_direction = 1;
			}

			// 3. Przygotowanie docelowych współrzędnych
			// Domyślnie osie stoją w bazie, tylko jedna "pływa"
			float tx = DEMO_BASE_X;
			float ty = DEMO_BASE_Y;
			float tz = DEMO_BASE_Z;
			float tp = DEMO_BASE_P;

			if (demo_type == 'X') tx = demo_current_val;
			else if (demo_type == 'Y') ty = demo_current_val;
			else if (demo_type == 'Z') tz = demo_current_val;
			else if (demo_type == 'P') tp = demo_current_val;

			// 4. Przelicz i ruszaj
			compute_IK(tx, ty, tz, tp, 0.0f);

		}
    /* USER CODE END WHILE */

    /* USER CODE BEGIN 3 */
	}
  /* USER CODE END 3 */
}

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
/* USER CODE BEGIN 4 */
void init_motors(void) {
	// Kolejność w strukturze:
	// stepPort, stepPin, dirPort, dirPin, limitPort, limitPin,
	// currentDelay, configTargetDelay, targetDelay, maxDelay,
	// direction, lastStep, lastAccelUpdate, isHoming,
	// stepsToMove, totalStepsToMove, currentPos, currentPosFloat

	motors[0] = (Stepper){GPIOC, GPIO_PIN_6, GPIOB, GPIO_PIN_15, GPIOE, GPIO_PIN_11, 2000, 300, 300, 2000, 0, 0, 0, 0, 0, 0, 0, 0.0f};
	motors[1] = (Stepper){GPIOB, GPIO_PIN_9, GPIOB, GPIO_PIN_12, GPIOE, GPIO_PIN_14, 2000, 300, 300, 2000, 0, 0, 0, 0, 0, 0, 0, 0.0f};
	motors[2] = (Stepper){GPIOA, GPIO_PIN_15, GPIOC, GPIO_PIN_7, GPIOE, GPIO_PIN_13, 2000, 300, 300, 2000, 0, 0, 0, 0, 0, 0, 0, 0.0f};
	motors[3] = (Stepper){GPIOB, GPIO_PIN_5, GPIOB, GPIO_PIN_3, NULL, 0, 2000, 1000, 1000, 2000, 0, 0, 0, 0, 0, 0, 0, 0.0f};
	motors[4] = (Stepper){GPIOA, GPIO_PIN_4, GPIOB, GPIO_PIN_4, NULL, 0, 2000, 300, 300, 2000, 0, 0, 0, 0, 0, 0, 0, 0.0f};

	for(int i = 0; i < 5; i++) {
		// Obliczamy startową pozycję matematyczną na podstawie kątów HOME
		float home_steps = home_angles[i] * steps_per_deg[i];
		motors[i].currentPosFloat = home_steps;
		motors[i].currentPos = (int32_t)roundf(home_steps);

		// Ważne: upewnij się, że stepsToMove i totalStepsToMove są na zero
		motors[i].stepsToMove = 0;
		motors[i].totalStepsToMove = 0;
	}
}

void HAL_TIM_PeriodElapsedCallback(TIM_HandleTypeDef *htim) {
    if (htim->Instance == TIM6) {

        uint8_t any_motor_active = 0;

        for (int i = 0; i < 5; i++) {
            // 1. Sprawdzamy, czy silnik ma wykonać krok
            if (motors[i].stepsToMove > 0) {
                any_motor_active = 1;

                // Licznik czasu dla każdego silnika osobno
                motors[i].lastStep++;

                if (motors[i].lastStep >= motors[i].currentDelay / 10) { // /10 bo timer tyka co 10us
                    HAL_GPIO_TogglePin(motors[i].stepPort, motors[i].stepPin);
                    motors[i].stepsToMove--;
                    motors[i].currentPos += motors[i].direction;
                    motors[i].lastStep = 0;
                }
            }
        }

        // 2. Logika bufora: Jeśli silniki skończyły i coś czeka w kolejce
        if (!any_motor_active && moveBuffer[bufferReadIdx].active) {
            load_next_segment();
        }
    }
}

void load_next_segment() {
    MoveSegment *seg = &moveBuffer[bufferReadIdx];

    for (int i = 0; i < 5; i++) {
        if (seg->steps[i] != 0) {
            // 1. Kierunek
            motors[i].direction = (seg->steps[i] > 0) ? 1 : -1;
            HAL_GPIO_WritePin(motors[i].dirPort, motors[i].dirPin,
                             (seg->steps[i] > 0) ? GPIO_PIN_SET : GPIO_PIN_RESET);

            // 2. Liczba kroków
            motors[i].stepsToMove = abs(seg->steps[i]);
            motors[i].totalStepsToMove = abs(seg->steps[i]);

            // 3. Synchronizacja prędkości
            // Ustawiamy docelową prędkość obliczoną dla tego konkretnego segmentu
            motors[i].targetDelay = seg->targetDelays[i];

            motors[i].lastStep = 0;
        } else{
        	motors[i].stepsToMove = 0;
        	motors[i].totalStepsToMove = 0;
        }
    }

    // Po załadowaniu zwolnij slot w buforze
    seg->active = 0;
    bufferReadIdx = (bufferReadIdx + 1) % MOVE_BUFFER_SIZE;
}

float clamp(float n, float min, float max) {
	if (n < min) return min;
	if (n > max) return max;
	return n;
}

void process_command(char* cmd) {
	if (strcmp(cmd, "HOME") == 0) {
		homing_active = 1;
		printf("Rozpoczynam bazowanie osi 1-3...\r\n");
		for(int i = 0; i < 3; i++) {
			// Ustawiamy kierunek w PRAWO (zgodnie z Twoją konfiguracją krańcówek)
			HAL_GPIO_WritePin(motors[i].dirPort, motors[i].dirPin, GPIO_PIN_SET);
			motors[i].direction = 1;
			motors[i].isHoming = 1;
			motors[i].stepsToMove = 1000000;
			motors[i].totalStepsToMove = 1000000;
		}
	} else if (strncmp(cmd, "DEMO:", 5) == 0) {
		char type = cmd[5]; // Pobieramy literę X, Y, Z lub P

		// Ustawiamy flagi sterujące
		demo_mode = 1;
		demo_type = type;
		demo_direction = 1;

		// Automatyczna konfiguracja zakresów na podstawie typu
		if (type == 'P') {
			demo_min = -80.0f; demo_max = -20.0f; demo_current_val = DEMO_BASE_P;
			demo_step = 0.1f;
		}else if (type == 'X') {
			demo_min = 200.0f; demo_max = 400.0f; demo_current_val = DEMO_BASE_X;
			demo_step = 1.0f;
		}else if (type == 'Y') {
			demo_min = -100.0f; demo_max = 100.0f; demo_current_val = DEMO_BASE_Y;
			demo_step = 1.0f;
		}else if (type == 'Z') {
			demo_min = 200.0f; demo_max = 400.0f; demo_current_val = DEMO_BASE_Z;
			demo_step = 1.0f;
		}

		printf("START DEMO %c: Jade do bazy...\r\n", type);
		// Pierwszy krok: Ruch do bezpiecznego punktu startowego
		compute_IK(DEMO_BASE_X, DEMO_BASE_Y, DEMO_BASE_Z, DEMO_BASE_P, 0.0f);

	} else if (strcmp(cmd, "STOP") == 0) {
		demo_mode = 0;
		printf("DEMO STOPPED\r\n");
	}
	if (cmd[0] == 'M') {
		int id = cmd[1] - '1';
		if (id < 0 || id > 4){
			return;
		}
		if (cmd[2] == 'V') { motors[id].targetDelay = atoi(&cmd[3]); motors[id].configTargetDelay = atoi(&cmd[3]);}
		else if (cmd[2] == 'L') { HAL_GPIO_WritePin(motors[id].dirPort, motors[id].dirPin, 0); motors[id].direction = -1; motors[id].stepsToMove = 1000000; motors[id].totalStepsToMove = 1000000; motors[id].currentDelay = motors[id].maxDelay;}
		else if (cmd[2] == 'R') { HAL_GPIO_WritePin(motors[id].dirPort, motors[id].dirPin, 1); motors[id].direction = 1; motors[id].stepsToMove = 1000000; motors[id].totalStepsToMove = 1000000; motors[id].currentDelay = motors[id].maxDelay;}
		else if (cmd[2] == 'S') {
			motors[id].direction = 0;
			motors[id].stepsToMove = 0;
			motors[id].totalStepsToMove = 0;
		}
	} else if (cmd[0] == 'S') {
		int id, val;
		if (sscanf(cmd, "S%d:%d", &id, &val) == 2) {
			if (id == 1) __HAL_TIM_SET_COMPARE(&htim2, TIM_CHANNEL_1, val);
			if (id == 2) __HAL_TIM_SET_COMPARE(&htim3, TIM_CHANNEL_1, val);
		}
	} else if (cmd[0] == 'G') {
		float x, y, z, p, r;
		// Zmieniony format: G:X,Y,Z,Pitch,Roll (np. G:300.0,0.0,400.0,-20.0,0.0)
		int n = sscanf(cmd, "G:%f,%f,%f,%f,%f", &x, &y, &z, &p, &r);

		if (n == 5) {
			printf("Obliczam IK dla: X=%.1f Y=%.1f Z=%.1f P=%.1f R=%.1f\r\n", x, y, z, p, r);
			compute_IK(x, y, z, p, r);
		} else {
			printf("Blad formatu! Uzyj G:X,Y,Z,P,R\r\n");
		}
	} else if (cmd[0] == 'R') {
		int id, steps;
		if (sscanf(cmd, "R%d:%d", &id, &steps) == 2) {
			id -= 1;
			if (id >= 0 && id < 5) {
				// 1. Obliczamy absolutną wartość kroków
				uint32_t abs_steps = abs(steps);

				if (abs_steps > 0) {
					// 2. Przygotowujemy silnik do ruchu z rampą
					motors[id].totalStepsToMove = abs_steps;
					motors[id].stepsToMove = abs_steps;
					motors[id].currentDelay = motors[id].maxDelay; // Start od wolnego tempa

					// 3. Ustawiamy kierunek
					if (steps > 0) {
						motors[id].direction = 1;
						HAL_GPIO_WritePin(motors[id].dirPort, motors[id].dirPin, GPIO_PIN_SET);
					} else {
						motors[id].direction = -1;
						HAL_GPIO_WritePin(motors[id].dirPort, motors[id].dirPin, GPIO_PIN_RESET);
					}

					ik_active = 1;
					printf("Ruch R%d o %d krokow z rampa\n", id + 1, steps);
				}
			}
		}
	} else if (cmd[0] == 'O'){
		int mode = atoi(&cmd[2]);
		if (mode == 1){
			current_max_ramp = 400;
		}else{
			current_max_ramp = 0;
		}
	}
}

void update_speed(int id) {
	// 1. Jeśli to bazowanie (Homing), używamy stałego, wolnego tempa
	if (motors[id].isHoming) {
		motors[id].currentDelay = 2000;
		return;
	}

	// 2. PRZYPADEK: Ruch o określoną liczbę kroków (IK, Demo, 'R')
	if (motors[id].stepsToMove > 0) {
		uint32_t stepsDone = motors[id].totalStepsToMove - motors[id].stepsToMove;
		uint32_t stepsLeft = motors[id].stepsToMove;
		uint32_t rampSize = motors[id].totalStepsToMove / 4;
		if (rampSize > current_max_ramp) rampSize = current_max_ramp;

		// --- LOGIKA BLENDINGU ---
		int nextIdx = (bufferReadIdx) % MOVE_BUFFER_SIZE; // bufferReadIdx wskazuje na następny, bo load_next_segment już go przesunął
		uint8_t next_active = moveBuffer[nextIdx].active;
		int8_t next_dir = (moveBuffer[nextIdx].steps[id] > 0) ? 1 : (moveBuffer[nextIdx].steps[id] < 0 ? -1 : 0);
		uint8_t same_direction = (next_dir == motors[id].direction);

		uint32_t calculatedDelay = motors[id].targetDelay;
		if (stepsDone < rampSize && stepsDone < stepsLeft) {
			// Rozpędzanie
			float factor = (float)stepsDone / (float)rampSize;
			calculatedDelay = motors[id].maxDelay - (uint32_t)((motors[id].maxDelay - motors[id].targetDelay) * factor);
			if (motors[id].currentDelay < calculatedDelay) {
				calculatedDelay = motors[id].currentDelay;
			}
		} else if (stepsLeft < rampSize && (!next_active || !same_direction)) {
			// Hamowanie
			float factor = (float)stepsLeft / (float)rampSize;
			calculatedDelay = motors[id].maxDelay - (uint32_t)((motors[id].maxDelay - motors[id].targetDelay) * factor);
		}
		// 2. AKTUALIZACJA
		motors[id].currentDelay = calculatedDelay;

		// Zabezpieczenie fizyczne (nie szybciej niż target)
		if (motors[id].currentDelay < motors[id].targetDelay) {
			motors[id].currentDelay = motors[id].targetDelay;
		}
	}
}

void compute_IK(float tx, float ty, float tz, float pitch_d, float roll_d) {
	float d2 = 70.5f; // Twoje przesunięcie barku w mm

	// --- 1. KĄT BAZY (Q1) Z OFFSETEM ---
	float R_total = sqrtf(tx * tx + ty * ty);

	if (R_total < d2) {
		printf("ALARM: Cel w martwej strefie offsetu!\r\n");
		printf("IK_DONE\r\n"); // Odblokuj GUI Pythona
		return;
	}

	float gamma = atan2f(ty, tx); // Kąt do punktu (X,Y)
	float alpha_off = asinf(d2 / R_total); // Kąt korekcyjny o offset

	// Uwaga: Zmień na + alpha_off jeśli robot skręca w drugą stronę niż powinien
	float q1_r = gamma - alpha_off;
	target_theta[0] = q1_r;

	// --- 2. POZYCJA NADGARSTKA (Wrist Center) ---
	float pr = pitch_d * (PI / 180.0f);

	// Rzut d6 na płaszczyznę XY musi być liczony wzdłuż linii ramion (nie linii tx,ty)
	float d6_xy = d6 * cosf(pr);
	float d6_z = d6 * sinf(pr);

	// WX i WY liczymy teraz uwzględniając, że oś ramion jest przesunięta o d2
	// Stosujemy obrót o kąt q1 i przesunięcie o d2
	float wx = tx - d6_xy * cosf(q1_r);
	float wy = ty - d6_xy * sinf(q1_r);
	float wz = tz - d6_z;

	// --- 3. GEOMETRIA RAMIENIA 2D ---
	// 'r' to teraz odległość w poziomie od osi barku do nadgarstka
	// Musimy ją wyliczyć w układzie lokalnym ramienia (po odjęciu offsetu d2)
	float R_wrist = sqrtf(wx * wx + wy * wy);
	float r = sqrtf(R_wrist * R_wrist - d2 * d2);

	float h = wz - d1;
	float s = sqrtf(r * r + h * h);

	// Twierdzenie cosinusów dla Q3 (Łokieć)
	float cos_q3 = (s * s - a2 * a2 - a3 * a3) / (2.0f * a2 * a3);
	cos_q3 = clamp(cos_q3, -1.0f, 1.0f);
	float q3_r = -acosf(cos_q3);
	target_theta[2] = q3_r;

	// Kąt Q2 (Ramię)
	float alpha = atan2f(h, r);
	float beta = atan2f(a3 * sinf(fabsf(q3_r)), a2 + a3 * cosf(q3_r));
	target_theta[1] = alpha + beta;

	// --- 4. ORIENTACJA I LIMITY ---
	float q2_d = target_theta[1] * (180.0f / PI);
	float q3_d = target_theta[2] * (180.0f / PI);
	target_theta[4] = (pitch_d - q2_d - q3_d) * (PI / 180.0f);
	target_theta[3] = roll_d * (PI / 180.0f);

	float q_deg[5];
	for(int i=0; i<5; i++) q_deg[i] = target_theta[i] * (180.0f / PI);

	if (q_deg[0] < -90.0f || q_deg[0] > 45.0f ||
		q_deg[1] < 10.0f || q_deg[1] > 135.0f ||
		q_deg[2] < -170.0f || q_deg[2] > 0.0f ||
		q_deg[3] < -90.0f || q_deg[3] > 90.0f ||
		q_deg[4] < -90.0f || q_deg[4] > 90.0f) {

		printf("ALARM: Limity przekroczone!\r\n");
		printf("Wyliczone: Q1:%.1f Q2:%.1f Q3:%.1f Q4:%.1f Q5:%.1f\r\n",
		q_deg[0], q_deg[1], q_deg[2], q_deg[3], q_deg[4]);

		printf("IK_DONE\r\n"); // KLUCZOWE: Odblokowanie Pythona w przypadku błędu
		return;
	}

	ik_active = 1;
	move_to_angles();
}

// Funkcja pomocnicza: oblicza szacowany czas trwania ruchu osi w mikrosekundach
uint32_t estimate_axis_time(int32_t steps, uint32_t targetD, uint32_t maxD) {
    uint32_t abs_steps = abs(steps);
    if (abs_steps == 0) return 0;

    // Obliczamy rampSize tak samo jak w update_speed
    uint32_t rampSize = abs_steps / 4;
    if (rampSize > current_max_ramp) rampSize = current_max_ramp;

    uint32_t cruiseSteps = 0;
    if (abs_steps > 2 * rampSize) {
        cruiseSteps = abs_steps - (2 * rampSize);
    } else {
        // Jeśli ruch jest tak mały, że nie ma fazy przelotowej
        rampSize = abs_steps / 2;
        cruiseSteps = 0;
    }

    // Średni delay podczas rampy to średnia arytmetyczna max i target
    float avgRampDelay = (maxD + targetD) / 2.0f;

    uint32_t timeRamping = (uint32_t)(2 * rampSize * avgRampDelay);
    uint32_t timeCruise = (uint32_t)(cruiseSteps * targetD);

    return timeRamping + timeCruise;
}
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

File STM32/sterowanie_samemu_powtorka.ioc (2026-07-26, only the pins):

Mcu.UserName=STM32H755ZITx
PA1.Signal=ETH_REF_CLK
PA11.Signal=USB_OTG_FS_DM
PA12.Signal=USB_OTG_FS_DP
PA2.Signal=ETH_MDIO
PA4.Signal=GPIO_Output
PA5.Signal=S_TIM2_CH1_ETR
PA6.Signal=S_TIM3_CH1
PA7.Signal=ETH_CRS_DV
PA8.Signal=USB_OTG_FS_SOF
PA9.Signal=USB_OTG_FS_VBUS
PB0.Signal=GPIO_Output
PB12.Signal=GPIO_Output
PB14.Signal=GPIO_Output
PB15.Signal=GPIO_Output
PB5.Signal=GPIO_Output
PB9.Signal=GPIO_Output
PC1.Signal=ETH_MDC
PC13.Signal=GPIO_Input
PC4.Signal=ETH_RXD0
PC5.Signal=ETH_RXD1
PC6.Signal=GPIO_Output
PC7.Signal=GPIO_Output
PD10.GPIO_Label=USB_OTG_FS_PWR_EN
PD10.Signal=GPIO_Output
PD8.Signal=USART3_TX
PD9.Signal=USART3_RX
PE1.Signal=GPIO_Output
PE11.Signal=GPIO_Input
PE13.Signal=GPIO_Input
PE14.Signal=GPIO_Input
PG11.Signal=ETH_TX_EN
PG13.Signal=ETH_TXD0
PG7.GPIO_Label=USB_OTG_FS_OVCR
PG7.Signal=GPXTI7

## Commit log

2026-07-26 All drawings
    [chwytak_koniec.FCStd, druga_os_zebatka_wieksza_dziura.FCStd, gora_obrotowa.FCStd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]
2026-09-24 Enhance README with project details and structure
    Expanded the README to include sections on introduction, design, electronics, actuation, and control software for the 6-axis robotic arm project.
2026-09-27 Update README for clarity and content adjustments
    Clarified the description of the robotic arm project and removed the 'Complete ownership' point.

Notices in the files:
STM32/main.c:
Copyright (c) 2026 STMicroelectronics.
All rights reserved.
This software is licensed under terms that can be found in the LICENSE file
